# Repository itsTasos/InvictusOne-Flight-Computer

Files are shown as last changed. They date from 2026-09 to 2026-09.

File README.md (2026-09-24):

# InvictusOne Flight Computer

A 4-layer flight-data acquisition and logging board for high-power model rockets. The design combines a 3S LiPo power front end, an STM32G474 microcontroller, multiple flight sensors, non-volatile storage, CAN-FD and UART interfaces, and an external watchdog.

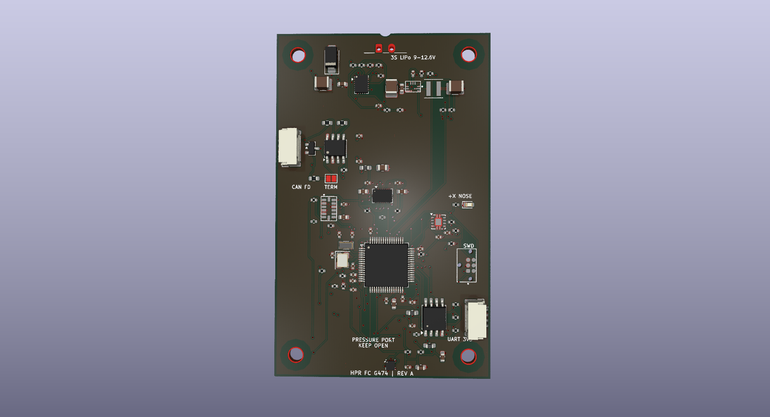
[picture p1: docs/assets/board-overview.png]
KiCad board layout


The board is intended to measure, timestamp, store, and communicate flight data. It does not include ignition, pyrotechnic, or recovery-deployment circuitry.

## Features

- STM32G474RET6 main controller with 8 MHz high-speed and 32.768 kHz low-speed crystals.
- BMI088 accelerometer and gyroscope, plus an ADXL375 high-g accelerometer with a measurement range up to ±200 g.
- LPS22DF absolute pressure sensor for pressure-based altitude estimation in application firmware.
- 128-Mbit (16-MiB) W25Q128 serial NOR flash for flight-data storage.
- CAN-FD transceiver with line protection and selectable 120 Ω termination.
- 3S battery input protection, electronic fuse, battery-current monitoring, and 3.3 V buck conversion.
- External watchdog connected to the MCU reset line.
- 29 test points on the bottom side.

## Specifications

| Item | Design specification |
|---|---|
| Battery input | 3S LiPo, 9.0–12.6 V nominal operating range |
| Battery protection | TPS25940 eFuse; nominal undervoltage rising/falling thresholds of about 8.67 V / 8.14 V, overvoltage cutoff about 13.53 V |
| Input current limit | About 1.74 A, set by the eFuse current-limit resistor |
| Main logic rail | 3.3 V from a TPS62902 synchronous buck converter |
| Sensor rails | 3V3_SENS and 3V3_BARO are ferrite-filtered branches of 3.3 V, not separate regulated outputs |
| Data storage | 128 Mbit / 16 MiB serial NOR flash |
| Communication | CAN-FD, 3.3 V UART, SWD |
| PCB outline | 50 × 80 mm |
| PCB construction | 4 copper layers, nominal 1.6 mm thickness |
| Mounting | Four 3.2 mm non-plated holes on a 40 × 70 mm pattern |
| Test access | 29 bottom-side test points |

Power thresholds and current limit are nominal resistor-based calculations. They are not per-cell LiPo protection thresholds or measured performance limits.

## Main components

| Reference | Part | Function |
|---|---|---|
| U1 | STM32G474RET6 | Main microcontroller; sensor acquisition, logging control, and communications |
| U2 | TPS3431SQDRBRQ1 | External watchdog; its output can reset the MCU |
| U3 | BMI088 | Accelerometer and gyroscope |
| U4 | ADXL375BCCZ | High-g accelerometer, ±200 g range |
| U5 | LPS22DFTR | Absolute pressure sensor |
| U6 | W25Q128JVSIQ | 128-Mbit serial NOR flash |
| U7 | TCAN3413DR | CAN-FD physical-layer transceiver |
| U8 | TPS25940AQRVCRQ1 | Input eFuse, voltage monitoring, current limiting, and current monitor |
| U9 | TPS62902QRYTRQ1 | Battery-to-3.3 V buck converter |
| U10 | PESD2CANFD24VT-Q | CAN bus transient protection |
| D2 | SMAJ13A-TR | Battery-input TVS diode |
| L1 | XGL4020-102ME, 1 µH | Buck-converter power inductor |

## Power and signal architecture

Battery power enters J1 as VBAT_RAW. The input TVS and eFuse feed VBAT_PROTECTED, which supplies the 3.3 V buck converter and is also available at J2 pin 1. The buck output is 3V3_MAIN. Ferrite filters create the 3V3_SENS branch for the inertial sensors, the 3V3_BARO branch for the pressure sensor, and a filtered VDDA branch for the MCU ADC.

The BMI088 uses SPI1, the ADXL375 uses SPI2, the pressure sensor uses I2C3, and the external flash uses SPI3. The MCU connects to the CAN-FD transceiver through FDCAN1, to J3 through USART2, and to a debug probe through SWD at J4. All board domains share a common ground; the sensor supply branches are filtered but not galvanically isolated.

See [Hardware design](docs/hardware-design.md) for the power path and design calculations, [Connector pinout](docs/pinout.md) for connector and test-point details, and [Programming and debug](docs/programming.md) for the custom SWD connection.

## External connectors

| Connector | Pin | Signal |
|---|---:|---|
| J1 — battery | 1 | VBAT_RAW, battery positive |
|  | 2 | GND |
| J2 — CAN module bus | 1 | VBAT_PROTECTED, battery voltage |
|  | 2 | GND |
|  | 3 | CAN_H |
|  | 4 | CAN_L |
| J3 — UART | 1 | 3V3_MAIN |
|  | 2 | GND |
|  | 3 | UART_TX from MCU |
|  | 4 | UART_RX to MCU |
| J4 — SWD | 1 | 3V3_MAIN / target reference |
|  | 2 | SWDIO |
|  | 3 | GND |
|  | 4 | SWCLK |
|  | 5 | GND |
|  | 6 | NRST |

**J2 pin 1 carries protected battery voltage, not 3.3 V.** J3 is a 3.3 V UART interface, not RS-232. J4 uses a custom six-contact assignment and is not the standard TC2030-CTX pinout. Confirm the pin numbering and cable wiring before connecting external equipment.

## Mechanical orientation

The board is 50 × 80 mm. The +X nose direction is marked on the silkscreen along the long board axis. The pressure-sensor port should remain unobstructed when installed. The four mounting holes are non-plated and form a 40 × 70 mm rectangle.

## Repository layout

- hardware/kicad/ — KiCad project, PCB, hierarchical schematic, design rules, and local symbol and footprint libraries.
- docs/schematic.pdf — rendered hierarchical schematic.
- docs/assets/board-overview.png — PCB layout illustration.
- docs/ — hardware overview, connector pinout, and programming guide.

## Opening the design

Open hardware/kicad/HPR_FC_G474_3S.kicad_pro in KiCad. The PCB, hierarchical schematic, local libraries, and design-rule file are kept together under hardware/kicad/; the project uses paths relative to that directory.

## Design boundaries

The board has no battery charger, cell balancer, individual-cell monitor, or guaranteed reverse-polarity protection. The eFuse monitors the pack input as a whole. Its nominal undervoltage threshold is below the safe minimum for some individual 3S LiPo cells, so it must not be used as cell-level protection.

The CAN interface is not galvanically isolated. The input TVS clamp can exceed the eFuse absolute-maximum input voltage under some surge conditions; validate the power source, wiring, and transient environment for the intended installation. This board is a sensing, logging, and communications platform, not a deployment controller.

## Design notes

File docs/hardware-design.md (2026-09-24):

# Hardware design

## Functional overview

The board routes a 3S LiPo input through a transient suppressor and an electronic fuse, then converts the protected battery rail to 3.3 V. The STM32G474 reads the sensors, monitors power, controls the external watchdog, communicates over CAN-FD and UART, and accesses external serial flash for data storage.

The inertial sensors, pressure sensor, MCU, CAN interface, watchdog, and flash share a common ground. Sensor supply branches use ferrite beads and local capacitors for filtering; they are not independent regulators or isolated domains.

## Power path

1. J1 provides VBAT_RAW and ground. D2 (SMAJ13A) is connected across the input for transient suppression.
2. U8 (TPS25940A) provides eFuse functions including undervoltage and overvoltage monitoring, current limiting, controlled output rise, fault indication, and analog current monitoring.
3. VBAT_PROTECTED feeds U9 and is also routed to J2 pin 1.
4. U9 (TPS62902) and L1 generate 3V3_MAIN.
5. FB1 and FB2 with local capacitance form filtered 3V3_SENS and 3V3_BARO branches. FB3 optionally filters the MCU VDDA branch.

With R22 = 442 kΩ, R23 = 20.5 kΩ, and R24 = 36.5 kΩ, nominal resistor-based thresholds are approximately:

| Parameter | Nominal calculation | Result |
|---|---|---:|
| Undervoltage rising | 0.99 × 499 / 57 | 8.67 V |
| Undervoltage falling | 0.93 × 499 / 57 | 8.14 V |
| Overvoltage cutoff | 0.99 × 499 / 36.5 | 13.53 V |
| eFuse current limit | 89 / 51.1, using R25 = 51.1 kΩ | 1.74 A |

These are nominal calculations using the device's typical thresholds and selected resistor values. They are not measurements or cell-level battery protection limits. R32 = 150 kΩ and R33 = 27.4 kΩ divide VBAT_PROTECTED to the MCU ADC. The eFuse current-monitor output is converted through R26 = 18.7 kΩ and routed to an ADC input.

## Processing and sensors

- U1, STM32G474RET6, is the central controller.
- U3, BMI088, provides accelerometer and gyroscope data over SPI1 with separate chip-select and data-ready signals.
- U4, ADXL375, provides high-g acceleration data over SPI2; its specified measurement range is ±200 g.
- U5, LPS22DF, measures absolute pressure over I2C3. Application firmware can use pressure readings to estimate relative altitude.
- U6, W25Q128JV, provides 128 Mbit (16 MiB) of SPI NOR storage over SPI3.
- Y1 and Y2 provide 8 MHz and 32.768 kHz clock references.
- U2, TPS3431, is an external watchdog connected to the MCU watchdog signals and reset net. Firmware must service and configure the watchdog appropriately.

## Communications

U7, TCAN3413, connects the MCU FDCAN1 peripheral to the CAN bus. U10 provides transient protection at the CAN connector. R19 and R20 are fitted 0 Ω links between the transceiver and bus. R21 is a 120 Ω termination resistor; JP1 controls whether the termination is connected. The CAN bus is not isolated.

J3 provides 3.3 V UART through USART2. J4 carries the custom SWD pinout described in [Programming and debug](programming.md).

## PCB and mechanical design

The board outline is 50 × 80 mm with four copper layers and nominal 1.6 mm thickness. Four 3.2 mm non-plated mounting holes use a 40 × 70 mm rectangular pattern. The long axis follows the +X nose direction marked on the board. The pressure-sensor port is identified on the silkscreen and should remain open to ambient pressure.

There are 29 test pads on the bottom side. Their signal groups are listed in [Connector pinout](pinout.md).

## Electrical boundaries

The board does not charge or balance a LiPo pack and does not measure individual cell voltages. The eFuse undervoltage threshold is for pack-level input control and should not be treated as per-cell battery protection. The design has no guaranteed reverse-battery protection. The SMAJ13A TVS clamp can exceed the eFuse absolute-maximum input voltage under some surge conditions, so the source, harness, and transient exposure must be suitable for the selected protection network.

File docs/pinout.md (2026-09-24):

# Connector pinout and test points

## External connectors

| Connector | Pin | Signal | Notes |
|---|---:|---|---|
| J1 — battery | 1 | VBAT_RAW | Battery positive, 9.0–12.6 V for a 3S LiPo |
|  | 2 | GND | Common board ground |
| J2 — CAN module bus | 1 | VBAT_PROTECTED | Protected battery voltage; not 3.3 V |
|  | 2 | GND | Common board ground |
|  | 3 | CAN_H | CAN-FD bus high |
|  | 4 | CAN_L | CAN-FD bus low |
| J3 — UART | 1 | 3V3_MAIN | 3.3 V output |
|  | 2 | GND | Common board ground |
|  | 3 | UART_TX | MCU transmit |
|  | 4 | UART_RX | MCU receive |
| J4 — SWD | 1 | 3V3_MAIN | Debugger target-voltage reference |
|  | 2 | SWDIO | SWD data |
|  | 3 | GND | Common board ground |
|  | 4 | SWCLK | SWD clock |
|  | 5 | GND | Common board ground |
|  | 6 | NRST | MCU reset |

J3 is 3.3 V UART, not RS-232. J4 is a custom pin assignment and does not follow the standard TC2030-CTX mapping. Confirm the connector orientation and pin numbering in the KiCad design before making a cable.

## MCU peripheral allocation

| Peripheral | Connected devices or interface |
|---|---|
| SPI1 | BMI088 |
| SPI2 | ADXL375 |
| SPI3 | W25Q128 serial flash |
| I2C3 | LPS22DF pressure sensor, 7-bit address 0x5C |
| FDCAN1 | TCAN3413 CAN-FD transceiver |
| USART2 | J3 UART connector |
| SWD | J4 debug connector |

The BMI088 accelerometer and gyroscope use separate chip-select signals on SPI1. The ADXL375 has two interrupt outputs. The pressure sensor has an interrupt output. The external watchdog is connected to the MCU reset network.

## Bottom-side test points

| Test point | Signal | Test point | Signal |
|---|---|---|---|
| TP1 | NRST | TP16 | FLASH_CS |
| TP2 | WDG_WDI | TP17 | CAN_H |
| TP3 | WDG_WDO / NRST | TP18 | CAN_L |
| TP4 | SPI1_SCK | TP19 | VBAT_RAW |
| TP5 | SPI1_MISO | TP20 | VBAT_PROTECTED |
| TP6 | SPI1_MOSI | TP21 | 3V3_MAIN |
| TP7 | SPI2_SCK | TP22 | 3V3_SENS |
| TP8 | SPI2_MISO | TP23 | 3V3_BARO |
| TP9 | SPI2_MOSI | TP24 | UART_TX |
| TP10 | I2C3_SCL | TP25 | UART_RX |
| TP11 | I2C3_SDA | TP26 | EFUSE_IMON |
| TP12 | BARO_INT | TP27 | VBAT_SENSE_ADC |
| TP13 | SPI3_SCK | TP28 | EFUSE_FLT |
| TP14 | SPI3_MISO | TP29 | BUCK_PGOOD |
| TP15 | SPI3_MOSI |  |  |

There is no dedicated ground test point; use a verified ground contact such as J1 pin 2. TP3 is labeled for watchdog output but is electrically on the NRST net.

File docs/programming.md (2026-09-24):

# Programming and debug

The STM32G474 is programmed over SWD through J4. The external W25Q128 serial NOR is intended for application data storage; it is not the MCU's program memory.

## J4 to STLINK-V3MINIE STDC14

| J4 pin | Board signal | STDC14 pin |
|---:|---|---:|
| 1 | 3V3_MAIN / target reference | 3, T_VCC |
| 2 | SWDIO | 4 |
| 3 | GND | 5 |
| 4 | SWCLK | 6 |
| 5 | GND | 7 |
| 6 | NRST | 12 |

This table maps electrical contacts, not cable colors. Verify the board connector orientation and continuity through the complete adapter before connecting a probe. J4 is not wired to the standard TC2030-CTX pinout.

## Connection sequence

1. With the board unpowered, connect the debugger to J4 using an adapter wired for the pin mapping above.
2. Power the board separately through J1. Use a supply appropriate for the board input range and observe current during initial power-up.
3. Connect with STM32CubeProgrammer using ST-LINK and SWD.
4. Program the STM32G474 application image, verify the write, and reset the board.

J4 pin 1 is a target-voltage reference from the board. It is not a battery input. Do not connect battery voltage to the debugger's VTref contact. J3 is a separate 3.3 V UART interface and is not RS-232.

## References

- [STLINK-V3MINIE user manual](https://www.st.com/resource/en/user_manual/um2910-stlinkv3minie-evaluation-board-stmicroelectronics.pdf)
- [TC2030-IDC-NL](https://www.tag-connect.com/product/tc2030-idc-nl)
- [STM32CubeProgrammer](https://www.st.com/en/development-tools/stm32cubeprog.html)

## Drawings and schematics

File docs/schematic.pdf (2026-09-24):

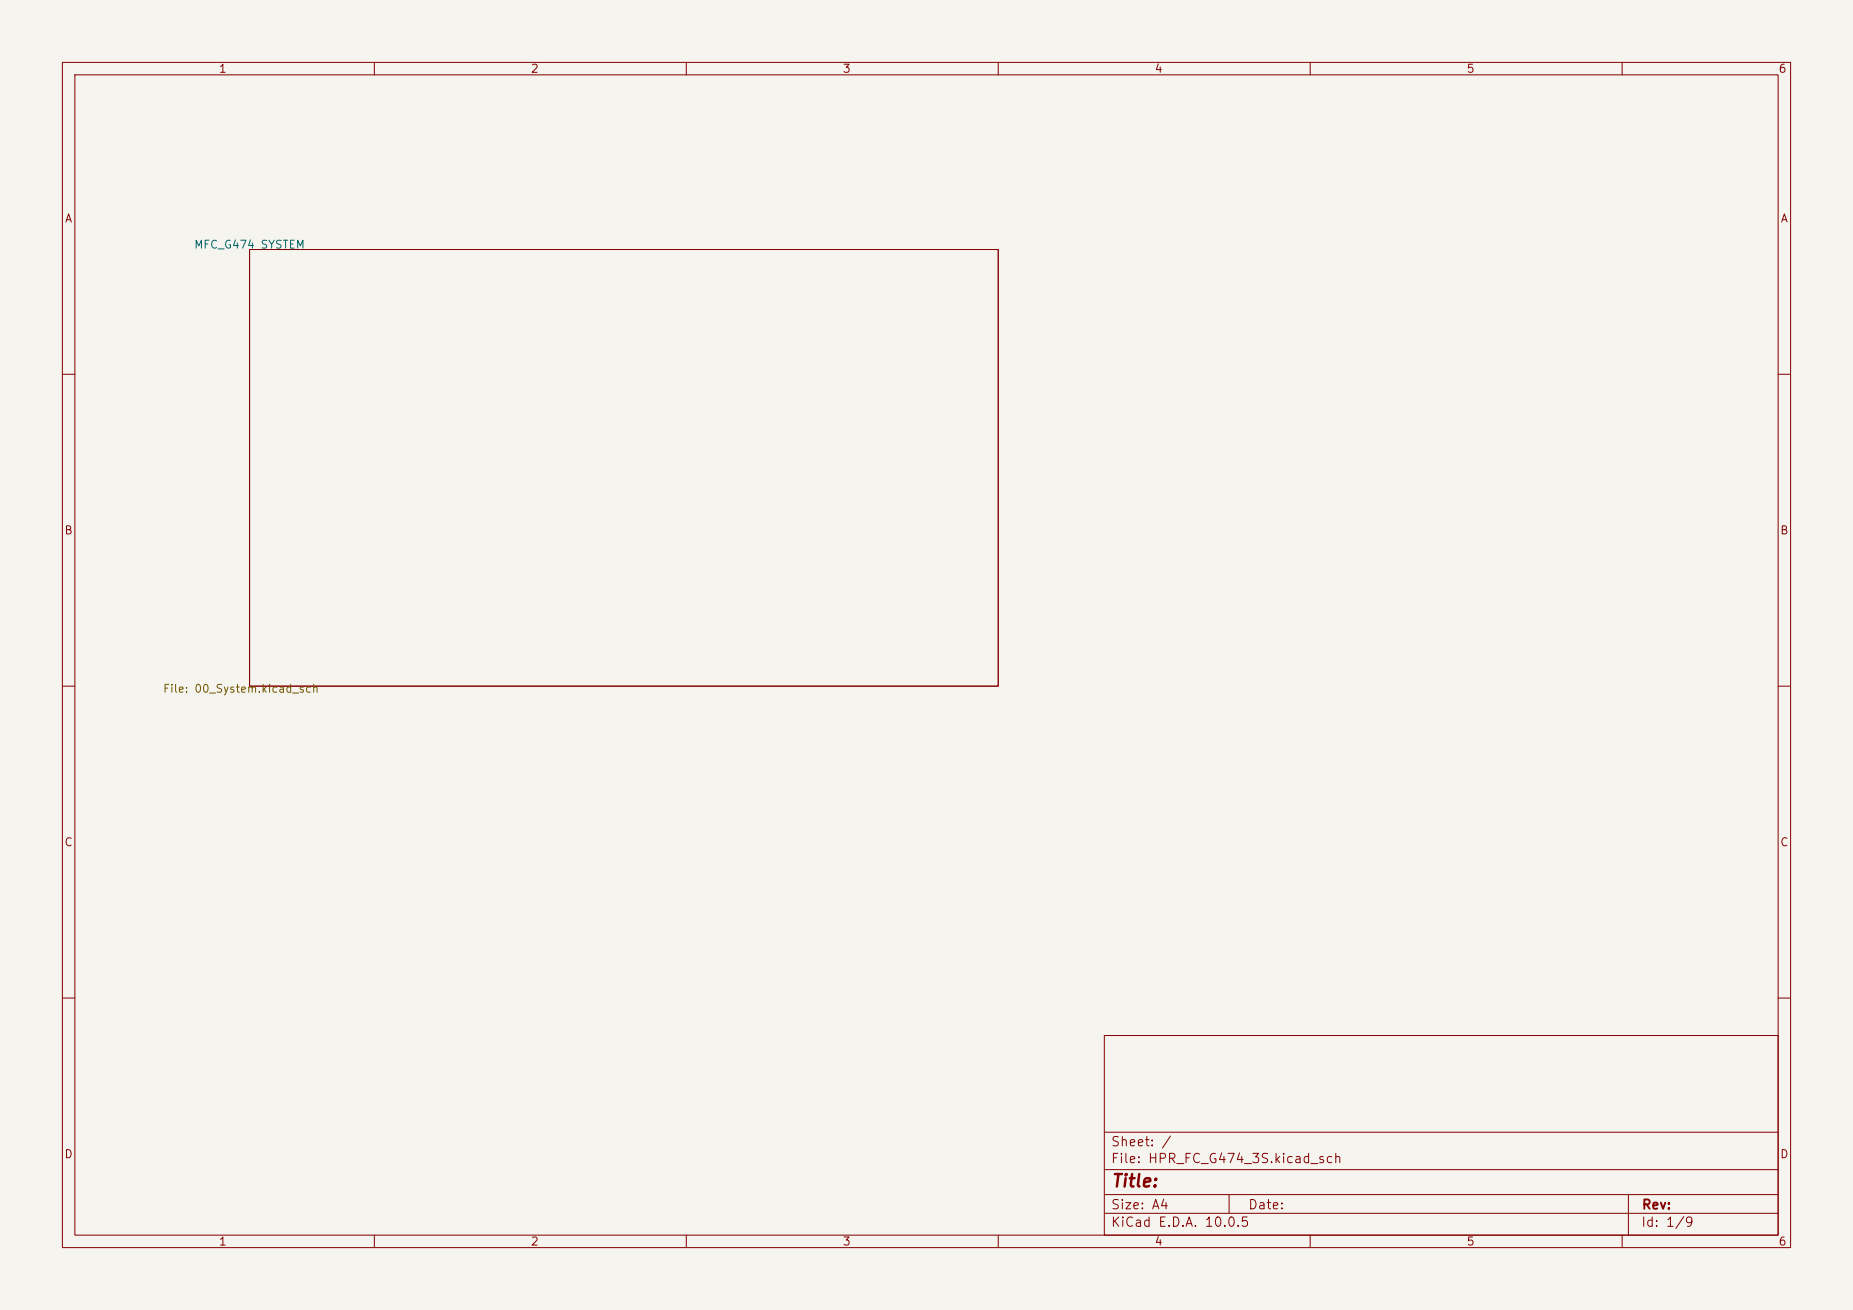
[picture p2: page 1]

Size: A4 | Rev:
KiCad E.D.A. 10.0.5 | Id: 1/9

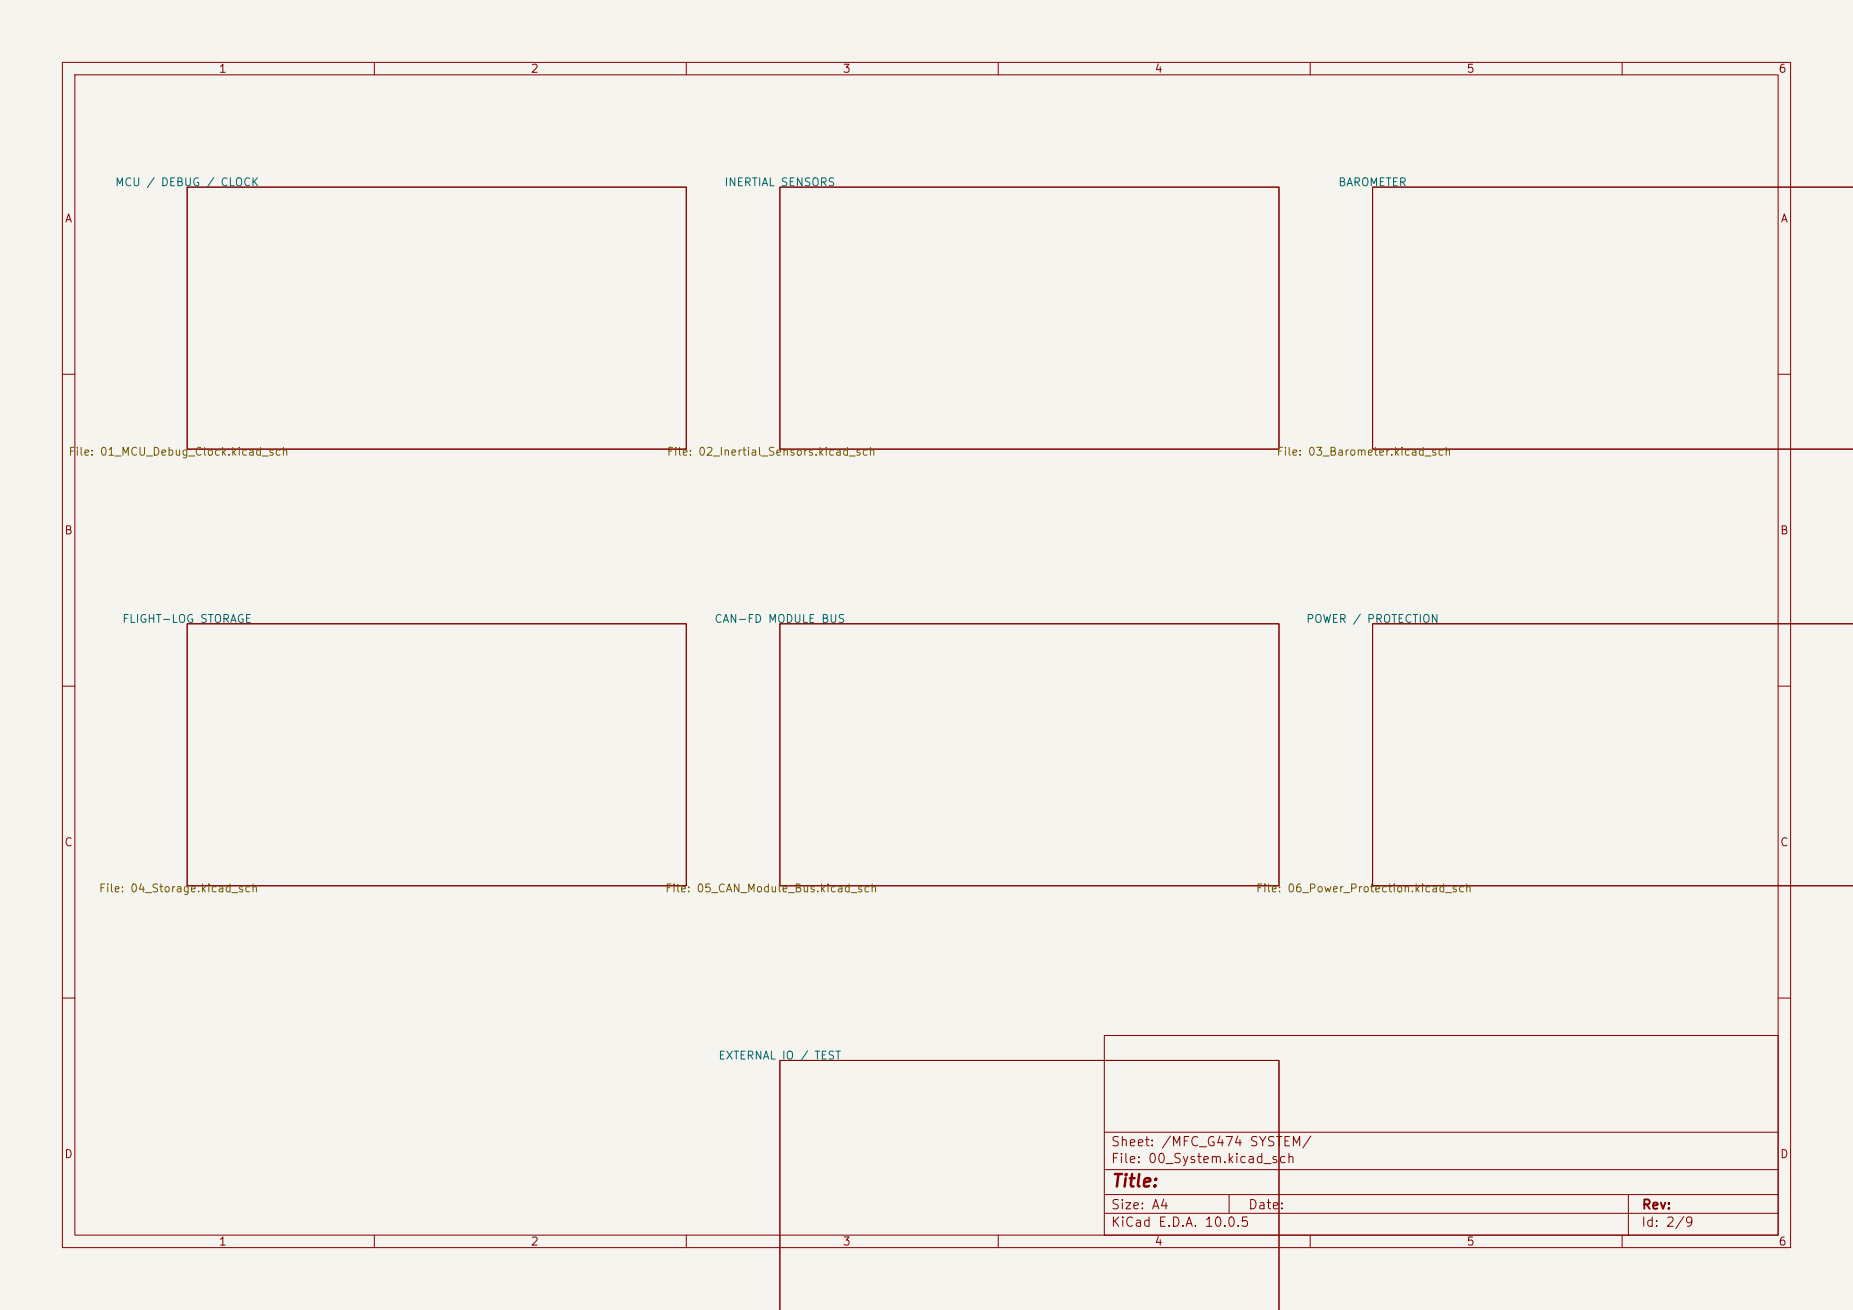
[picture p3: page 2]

File: 03_Barometer.kicad_sch MCU / DEBUG / CLOCK

EXTERNAL IO / TEST File: 07_External_IO.kicad_sch

Sheet: /MFC_G474 SYSTEM/ File: 00_System.kicad_sch | D Date:

Title:

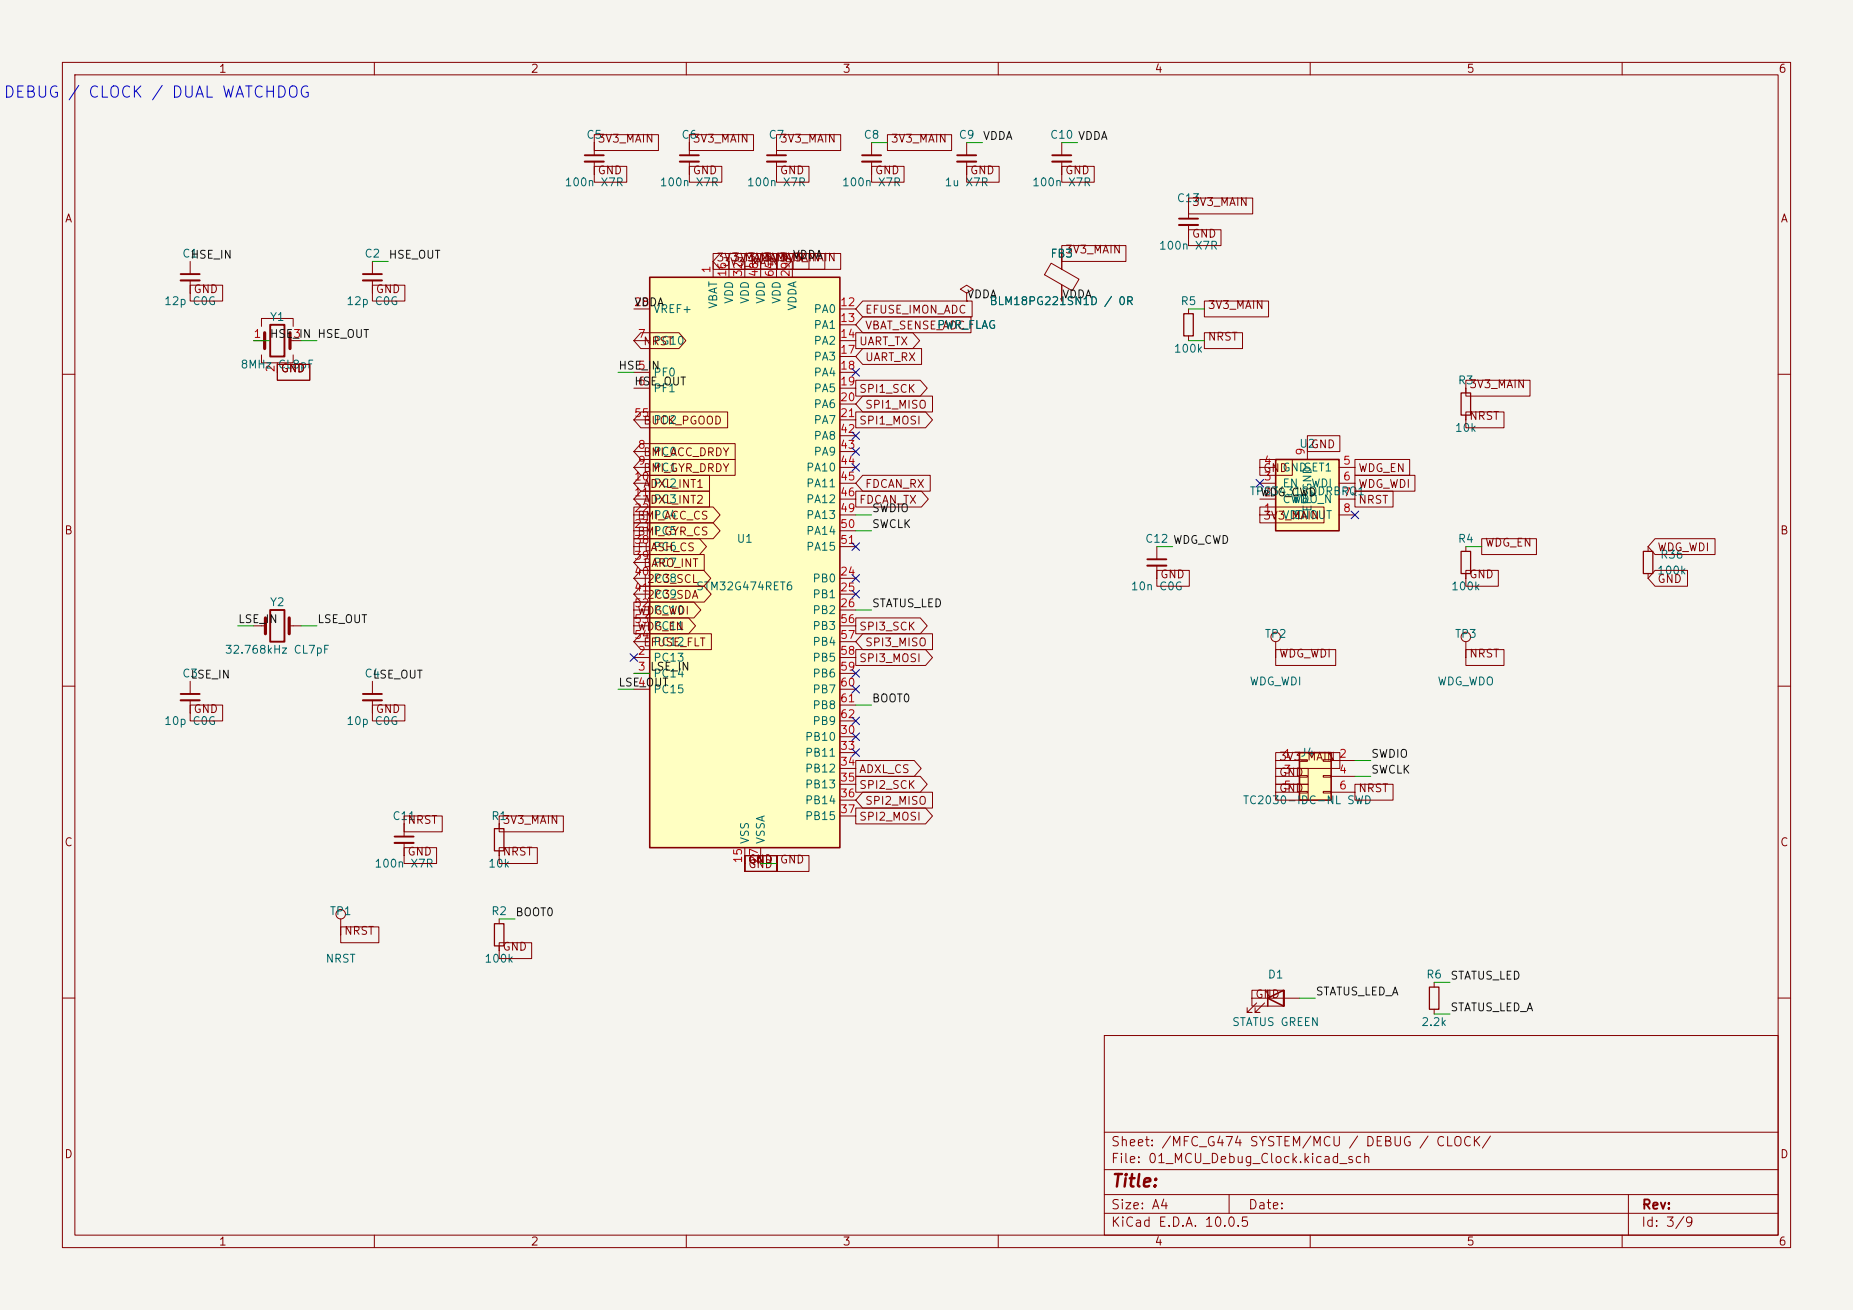
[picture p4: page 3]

VDDA MCU / DEBUG / CLOCK / DUAL WATCHDOG

Sheet: /MFC_G474 SYSTEM/MCU / DEBUG / CLOCK/
File: 01_MCU_Debug_Clock.kicad_sch
Title:

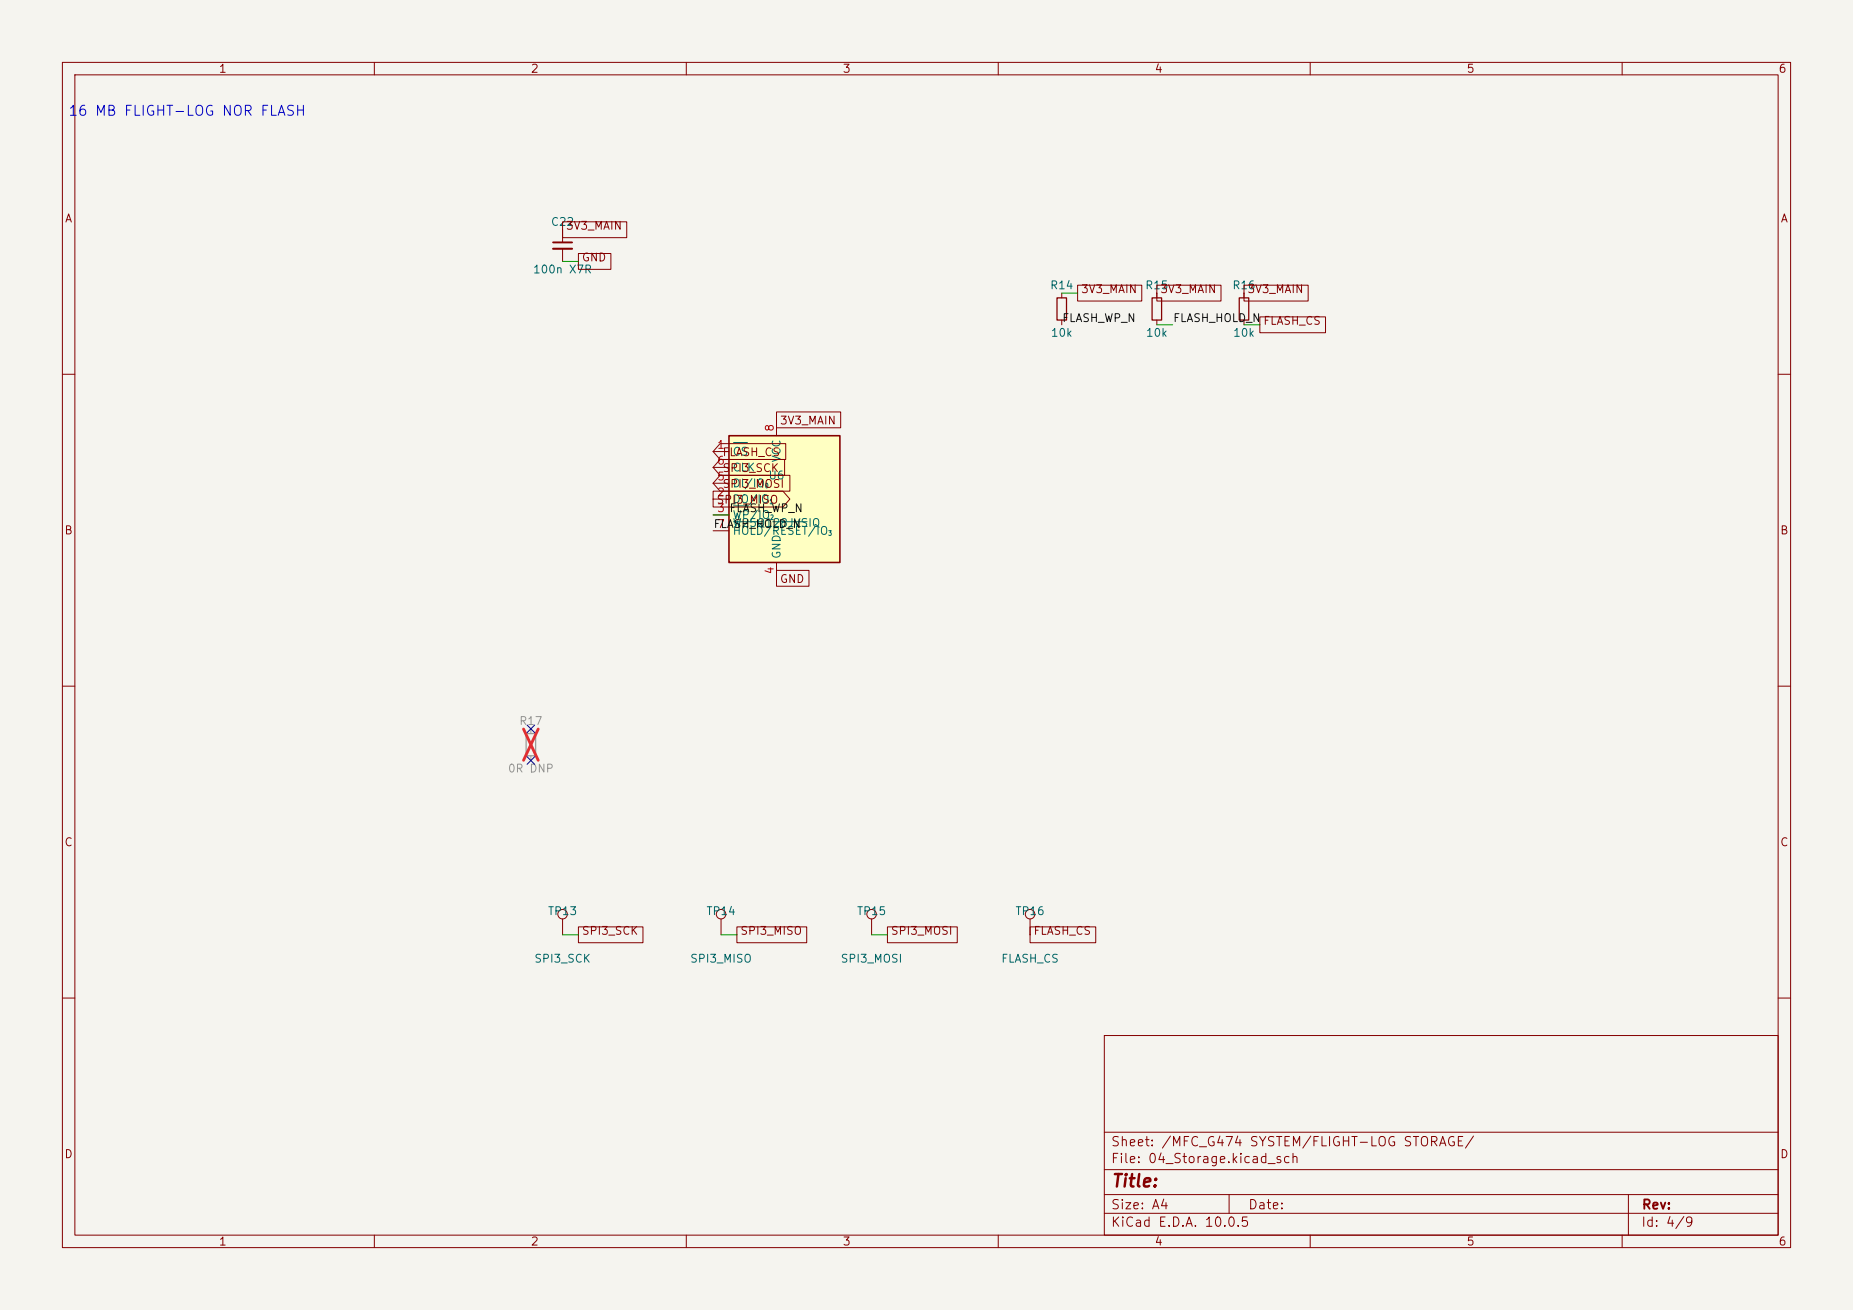
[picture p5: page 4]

FLASH_HOLD_N 16 MB FLIGHT-LOG NOR FLASH

4 DI/IO0 5 CLK 6 HOLD/RESET/IO3 7 VCC

Sheet: /MFC_G474 SYSTEM/FLIGHT-LOG STORAGE/
File: 04_Storage.kicad_sch
Title:

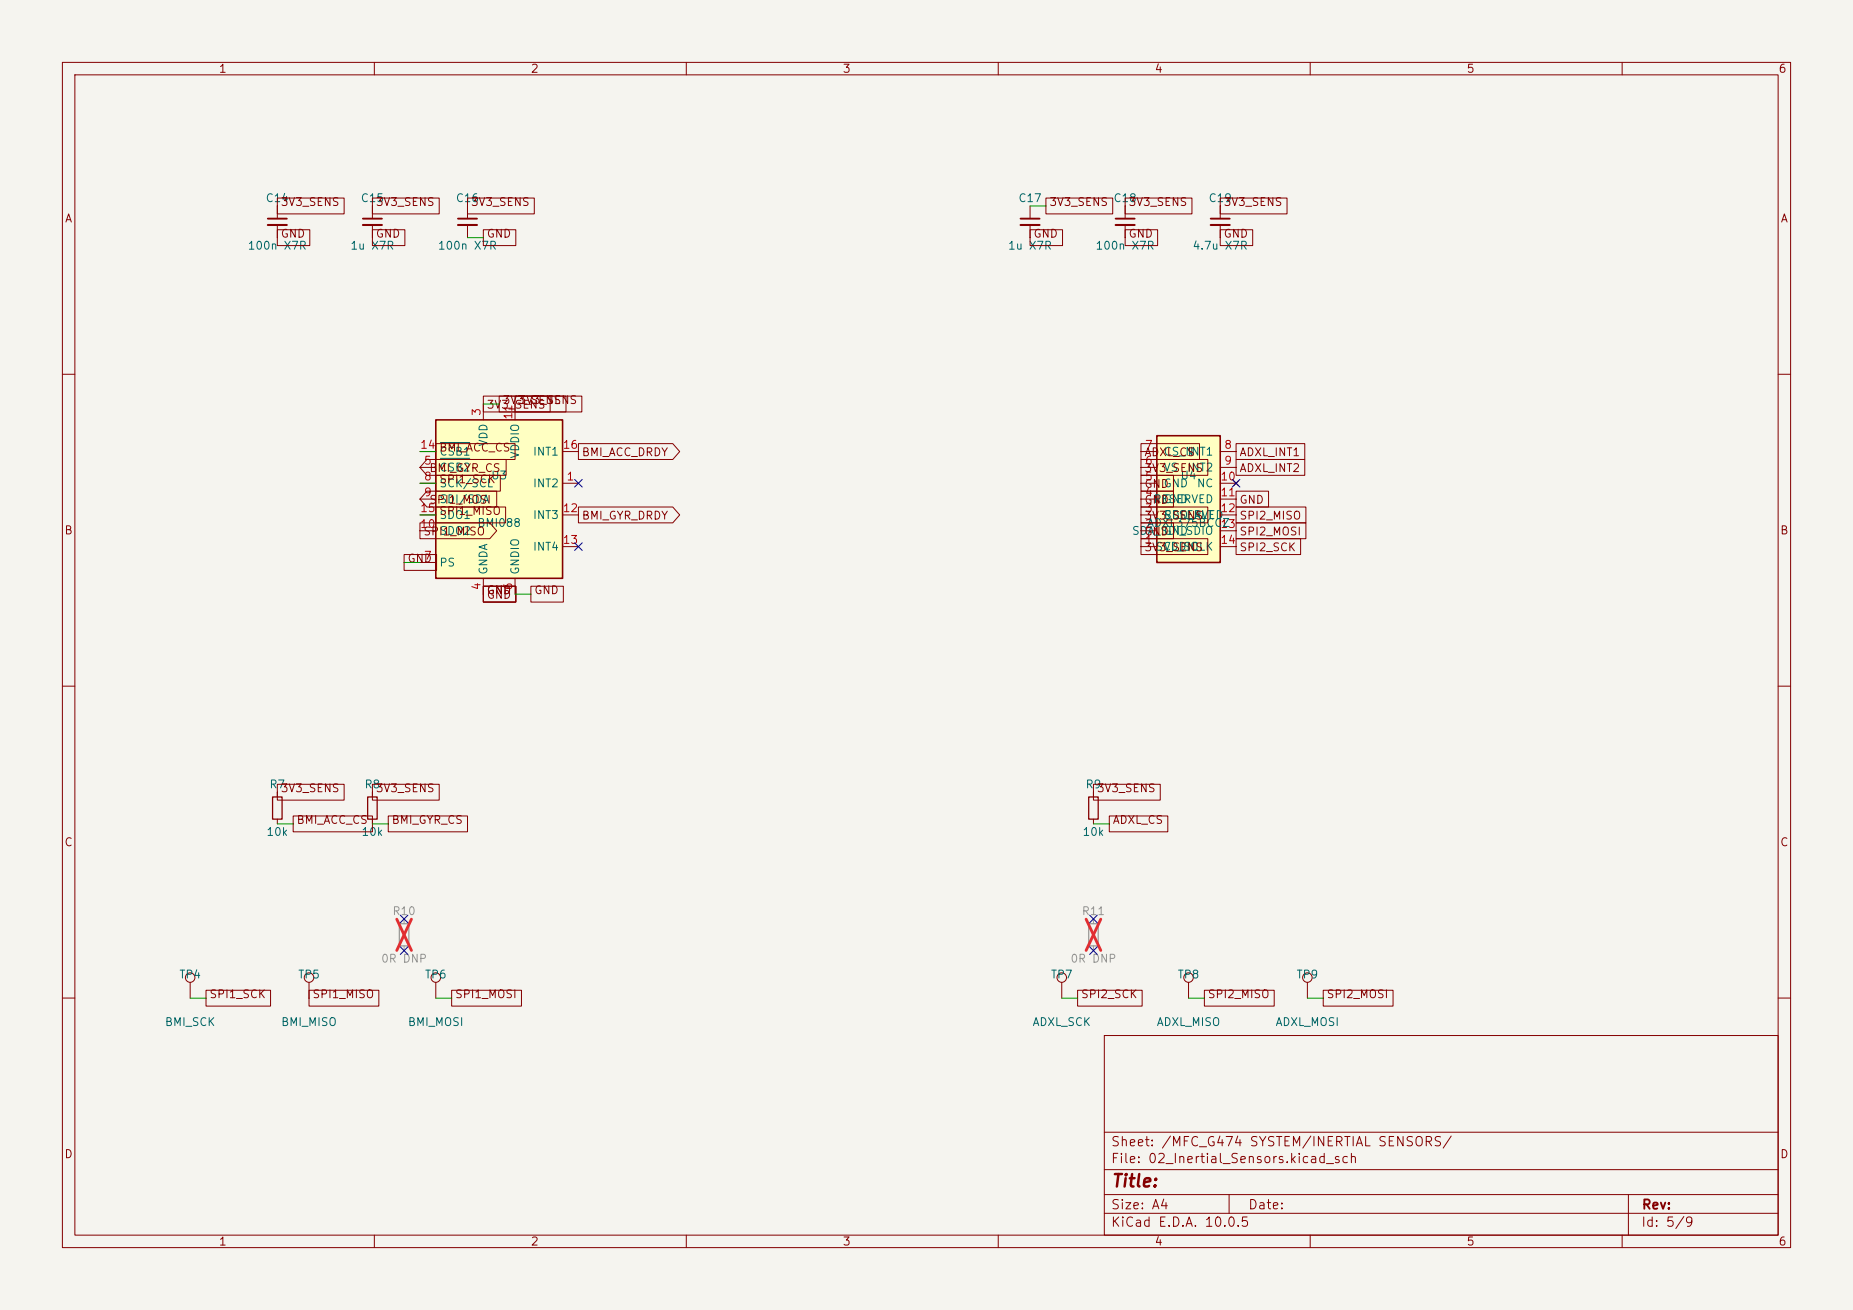
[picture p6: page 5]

Sheet: /MFC_G474 SYSTEM/INERTIAL SENSORS/
File: 02_Inertial_Sensors.kicad_sch
Title:

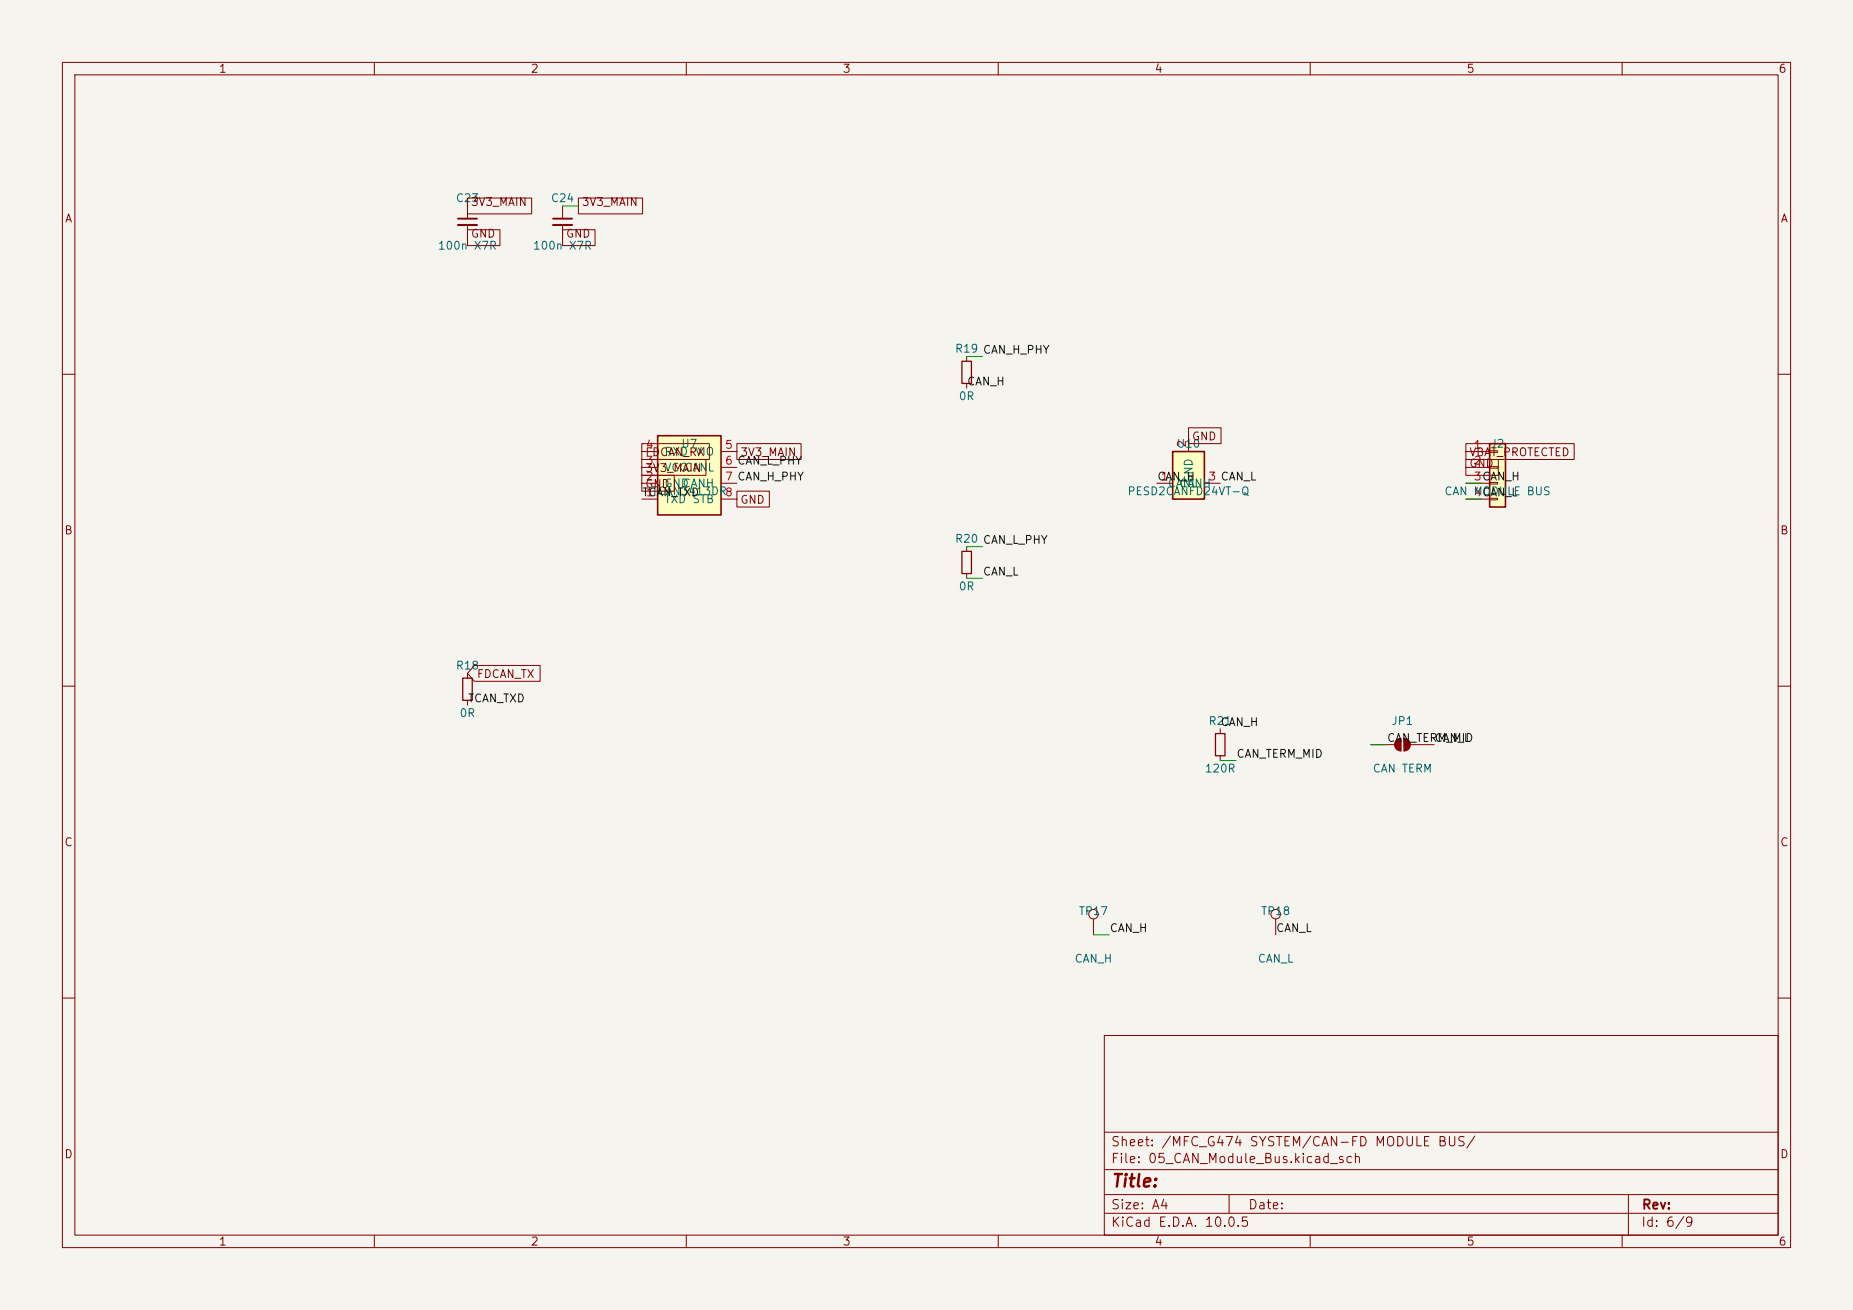
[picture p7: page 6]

Sheet: /MFC_G474 SYSTEM/CAN-FD MODULE BUS/
File: 05_CAN_Module_Bus.kicad_sch
Title:

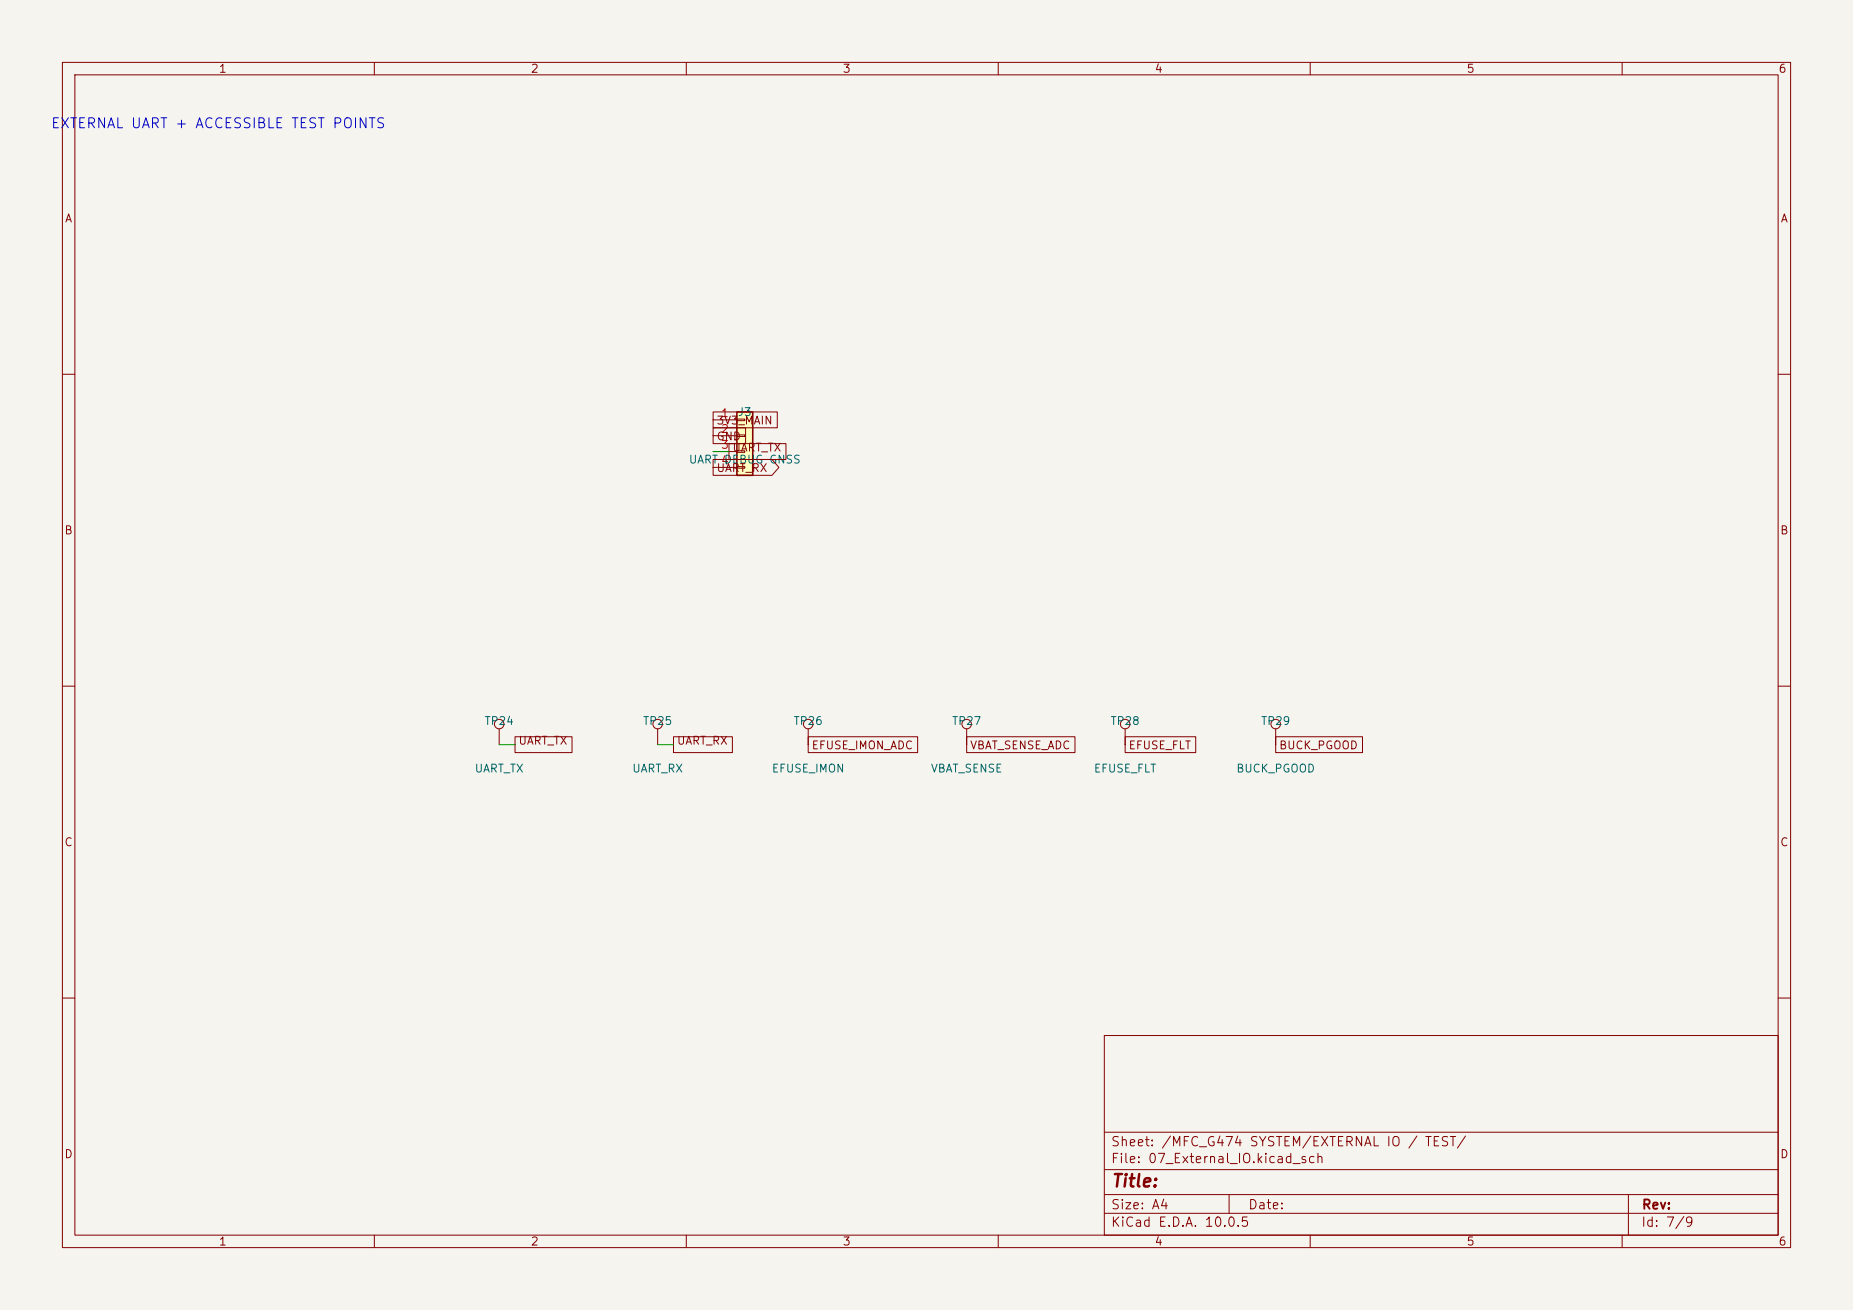
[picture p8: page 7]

UART_RX EXTERNAL UART + ACCESSIBLE TEST POINTS

Sheet: /MFC_G474 SYSTEM/EXTERNAL IO / TEST/
File: 07_External_IO.kicad_sch
Title:

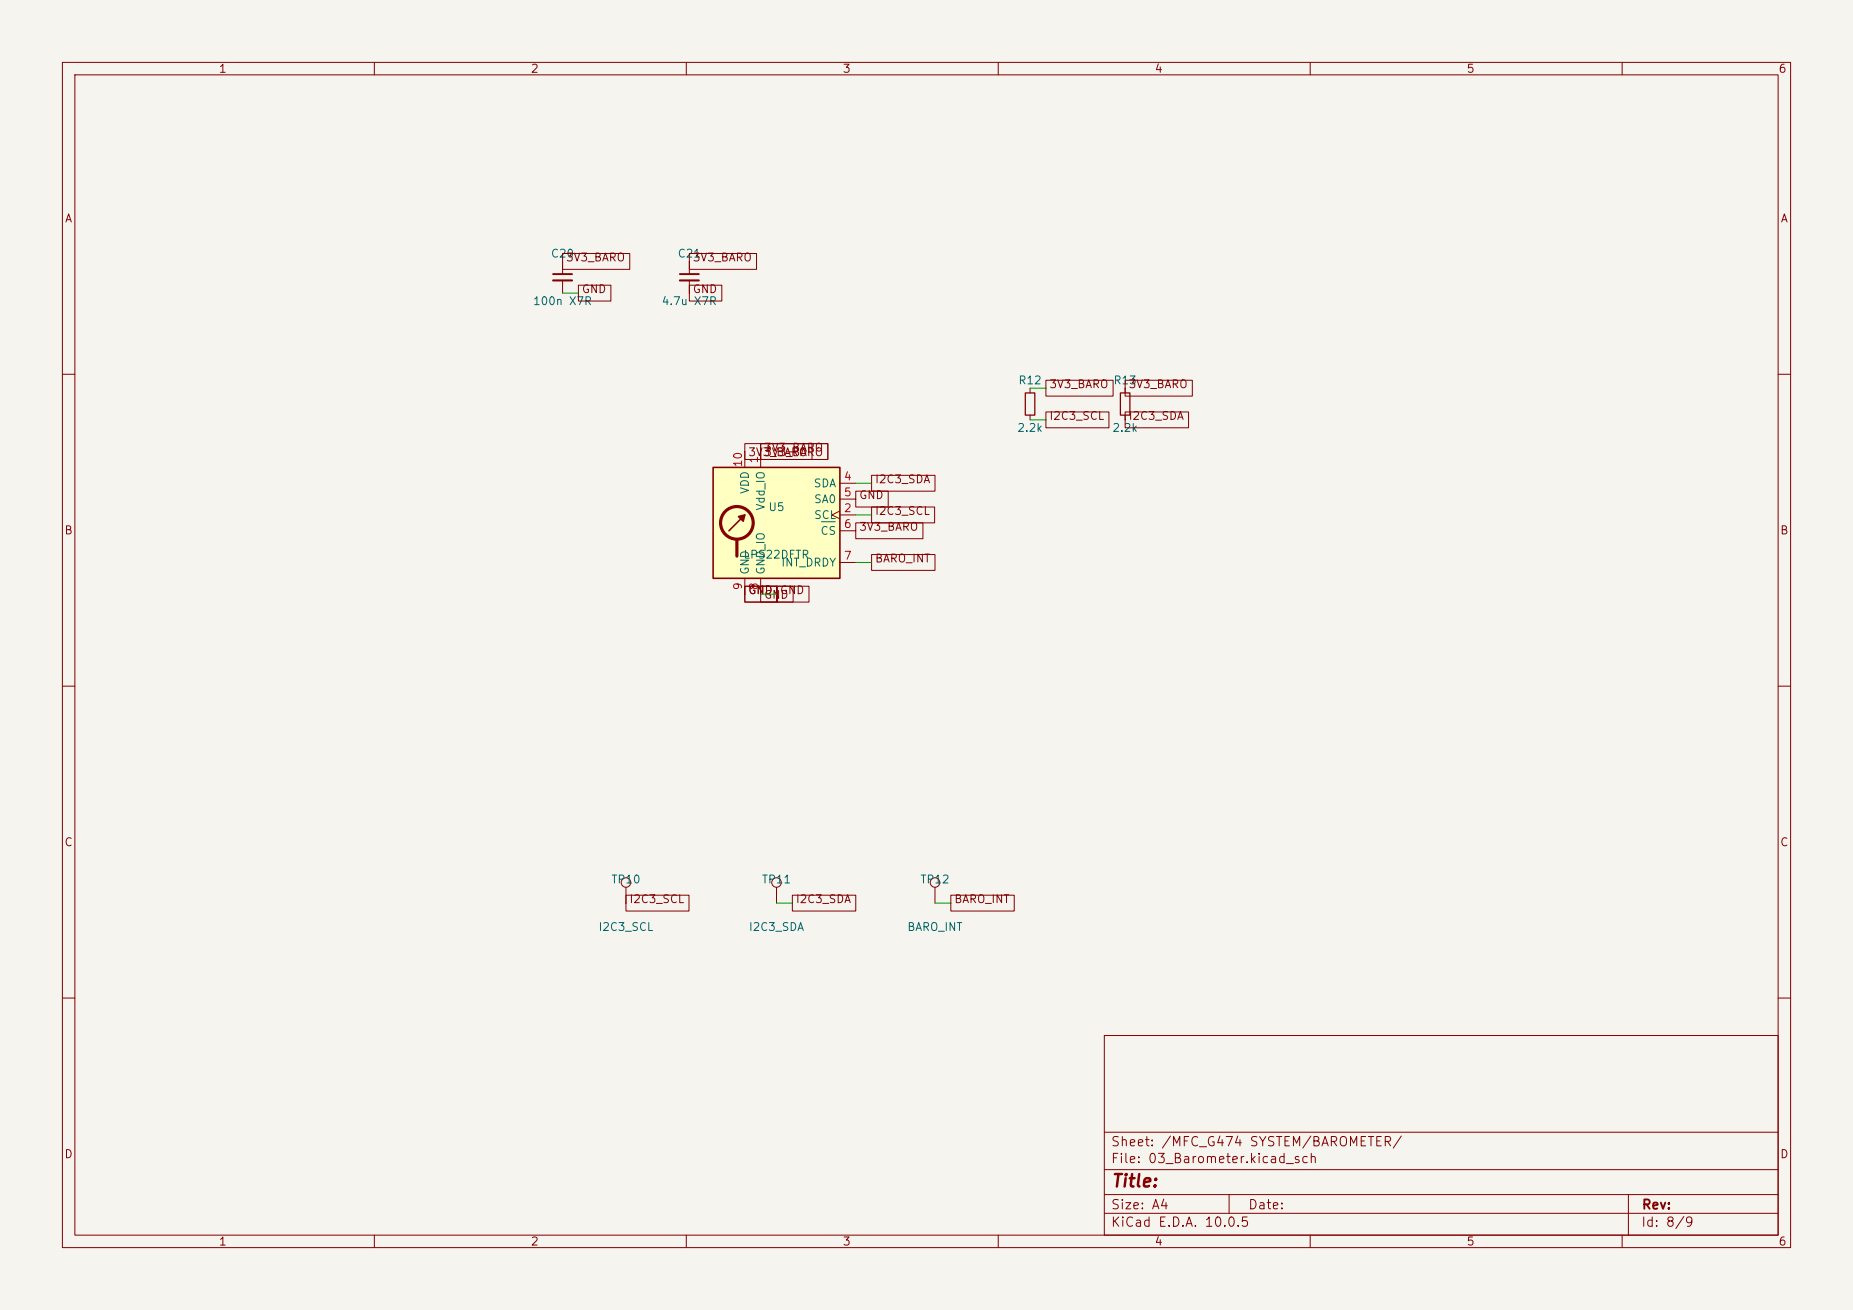
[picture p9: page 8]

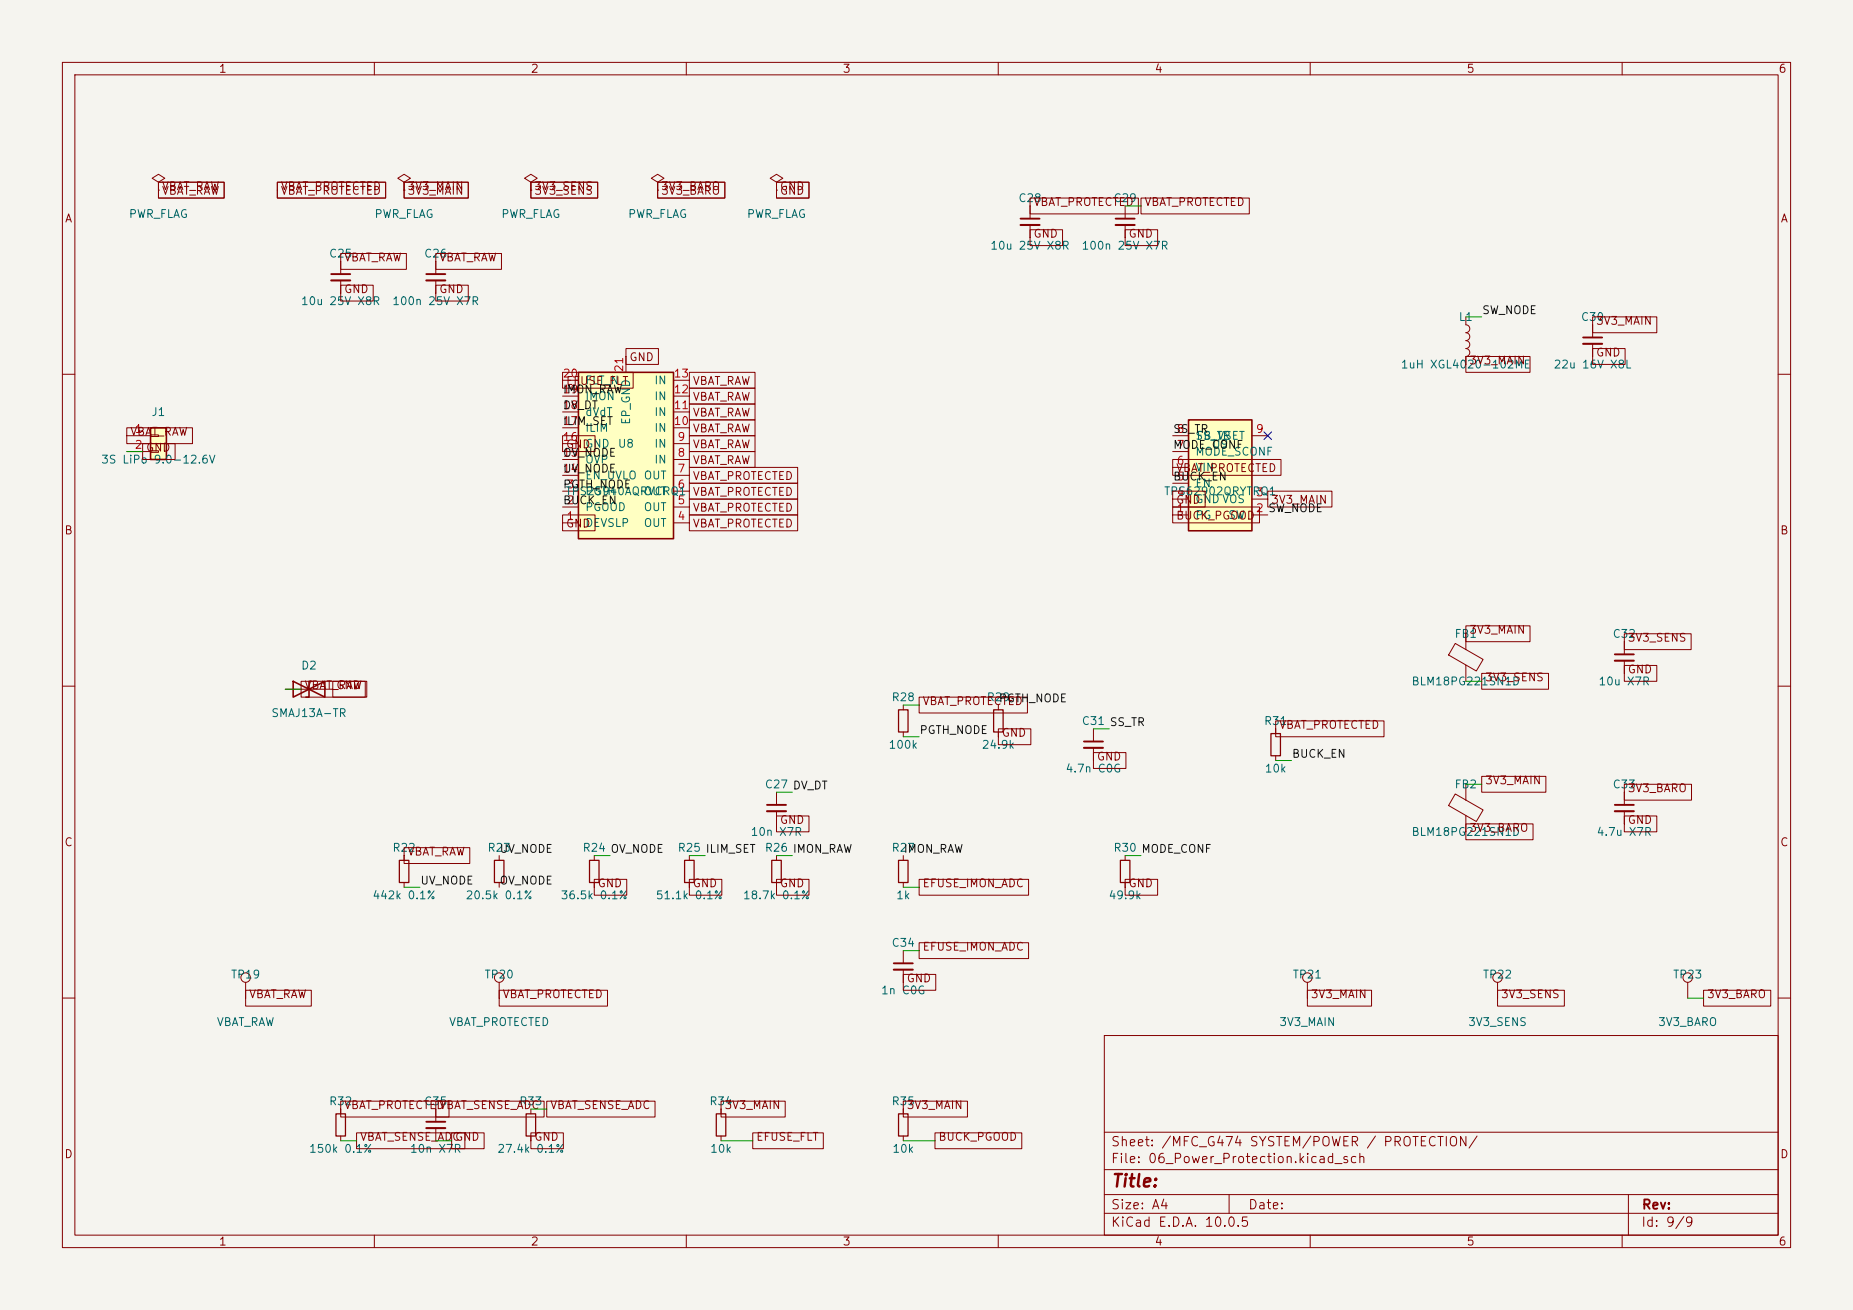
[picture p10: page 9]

Sheet: /MFC_G474 SYSTEM/POWER / PROTECTION/
File: 06_Power_Protection.kicad_sch
Title:

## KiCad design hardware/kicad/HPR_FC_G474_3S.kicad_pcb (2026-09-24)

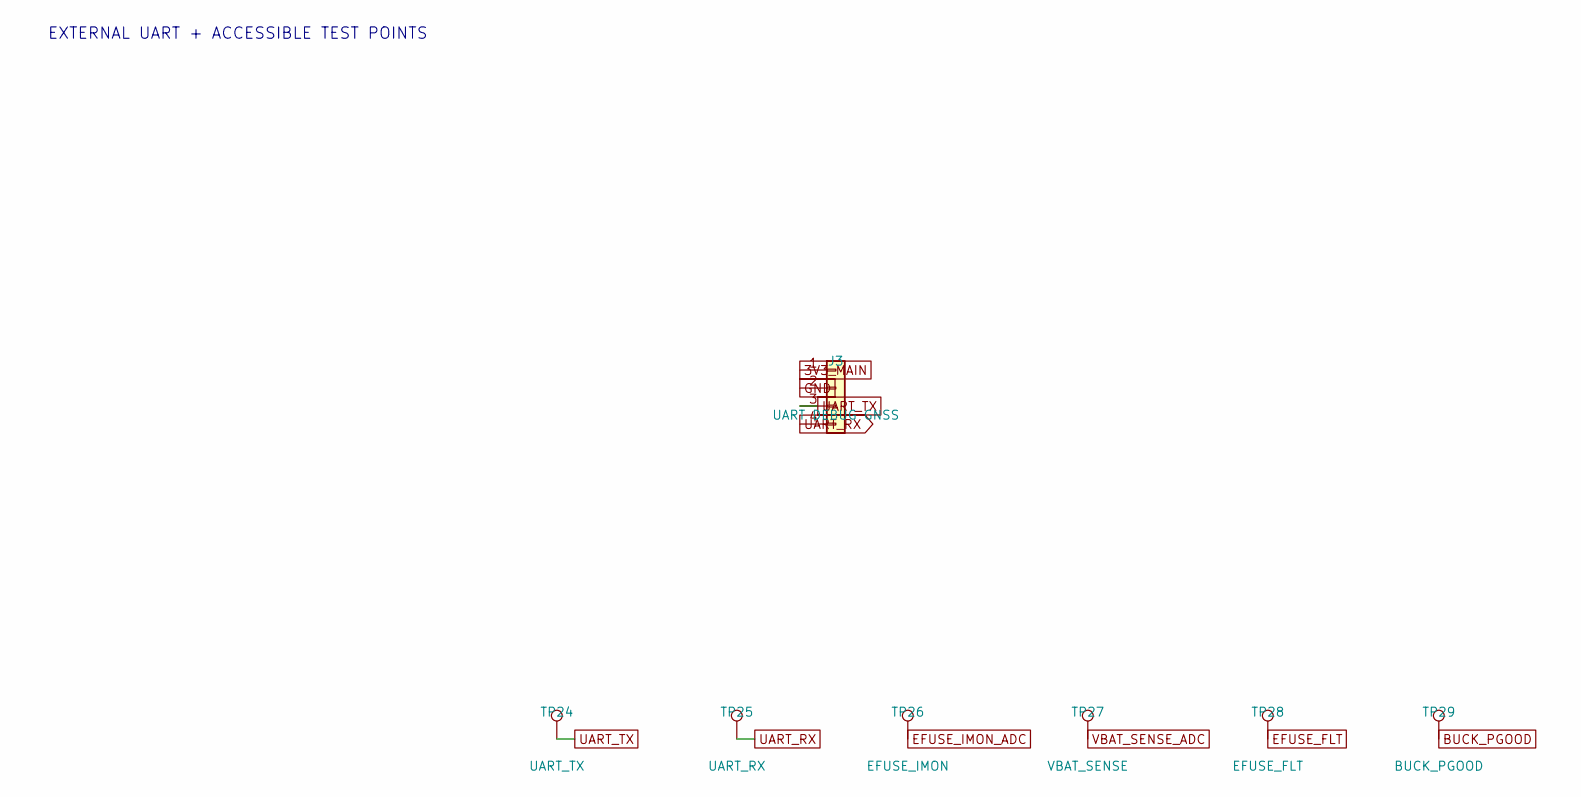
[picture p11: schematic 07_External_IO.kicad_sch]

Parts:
J3: UART DEBUG GNSS; JST_GH_SM04B-GHS-TB_1x04-1MP_P1.25mm_Horizontal
TP24: UART_TX; TestPoint_Pad_D1.0mm
TP25: UART_RX; TestPoint_Pad_D1.0mm
TP26: EFUSE_IMON; TestPoint_Pad_D1.0mm
TP27: VBAT_SENSE; TestPoint_Pad_D1.0mm
TP28: EFUSE_FLT; TestPoint_Pad_D1.0mm
TP29: BUCK_PGOOD; TestPoint_Pad_D1.0mm

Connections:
3V3_MAIN: J3.1; also elsewhere on the board
BUCK_PGOOD: TP29.1 (1_1); also elsewhere on the board
EFUSE_FLT: TP28.1 (1_1); also elsewhere on the board
EFUSE_IMON_ADC: TP26.1 (1_1); also elsewhere on the board
GND: J3.2; also elsewhere on the board
UART_RX: J3.4, TP25.1 (1_1); also elsewhere on the board
UART_TX: J3.3, TP24.1 (1_1); also elsewhere on the board
VBAT_SENSE_ADC: TP27.1 (1_1); also elsewhere on the board

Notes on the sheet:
EXTERNAL UART + ACCESSIBLE TEST POINTS

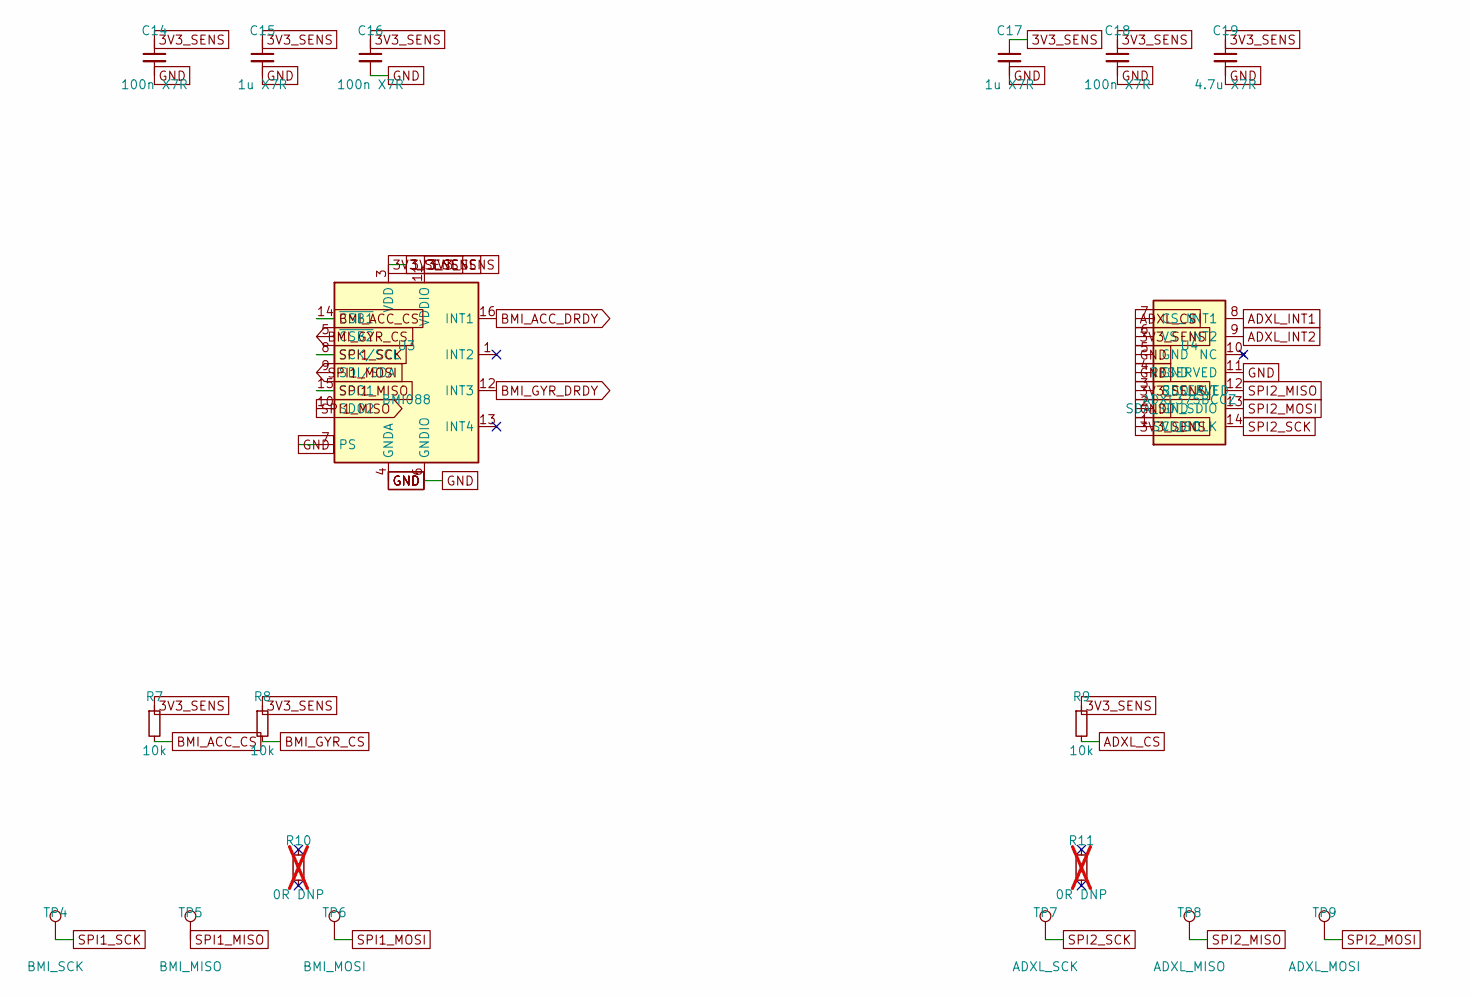
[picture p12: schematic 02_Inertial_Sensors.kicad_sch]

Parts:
C14, C16, C18: 100n X7R; C_0402_1005Metric
C15, C17: 1u X7R; C_0603_1608Metric
C19: 4.7u X7R; C_0603_1608Metric
R7, R8, R9: 10k; R_0402_1005Metric
R10, R11: 0R DNP; R_0402_1005Metric; not fitted
TP4: BMI_SCK; TestPoint_Pad_D1.0mm
TP5: BMI_MISO; TestPoint_Pad_D1.0mm
TP6: BMI_MOSI; TestPoint_Pad_D1.0mm
TP7: ADXL_SCK; TestPoint_Pad_D1.0mm
TP8: ADXL_MISO; TestPoint_Pad_D1.0mm
TP9: ADXL_MOSI; TestPoint_Pad_D1.0mm
U3: BMI088; Bosch_LGA-16_4.5x3mm_P0.5mm_LayoutBorder7x1y_ClockwisePinNu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; MPN BMI088
U4: ADXL375BCCZ; Analog_ADXL375_CC-14-1_LGA14_3x5mm_P0.8mm; MPN ADXL375BCCZ

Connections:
3V3_SENS: C14.1, C15.1, C16.1, C17.1, C18.1, C19.1, R7.1, R8.1, R9.1, U3.3 (VDD), U3.11 (VDDIO), U4.1 (VDDIO), U4.3 (RESERVED), U4.6 (VS); also elsewhere on the board
ADXL_CS: R9.2, U4.7 (CS_N); also elsewhere on the board
ADXL_INT1: U4.8 (INT1); also elsewhere on the board
ADXL_INT2: U4.9 (INT2); also elsewhere on the board
BMI_ACC_CS: R7.2, U3.14 (~CSB1); also elsewhere on the board
BMI_ACC_DRDY: U3.16 (INT1); also elsewhere on the board
BMI_GYR_CS: R8.2, U3.5 (~CSB2); also elsewhere on the board
BMI_GYR_DRDY: U3.12 (INT3); also elsewhere on the board
GND: C14.2, C15.2, C16.2, C17.2, C18.2, C19.2, U3.2 (GNDA), U3.4 (GNDA), U3.6 (GNDIO), U3.7 (PS), U4.2 (GND), U4.4 (GND), U4.5 (GND), U4.11 (RESERVED); also elsewhere on the board
SPI1_MISO: TP5.1 (1_1), U3.10 (SDO2), U3.15 (SDO1); also elsewhere on the board
SPI1_MOSI: TP6.1 (1_1), U3.9 (SDI/SDA); also elsewhere on the board
SPI1_SCK: TP4.1 (1_1), U3.8 (SCK/SCL); also elsewhere on the board
SPI2_MISO: TP8.1 (1_1), U4.12 (SDO_ALT); also elsewhere on the board
SPI2_MOSI: TP9.1 (1_1), U4.13 (SDA_SDI_SDIO); also elsewhere on the board
SPI2_SCK: TP7.1 (1_1), U4.14 (SCL_SCLK); also elsewhere on the board

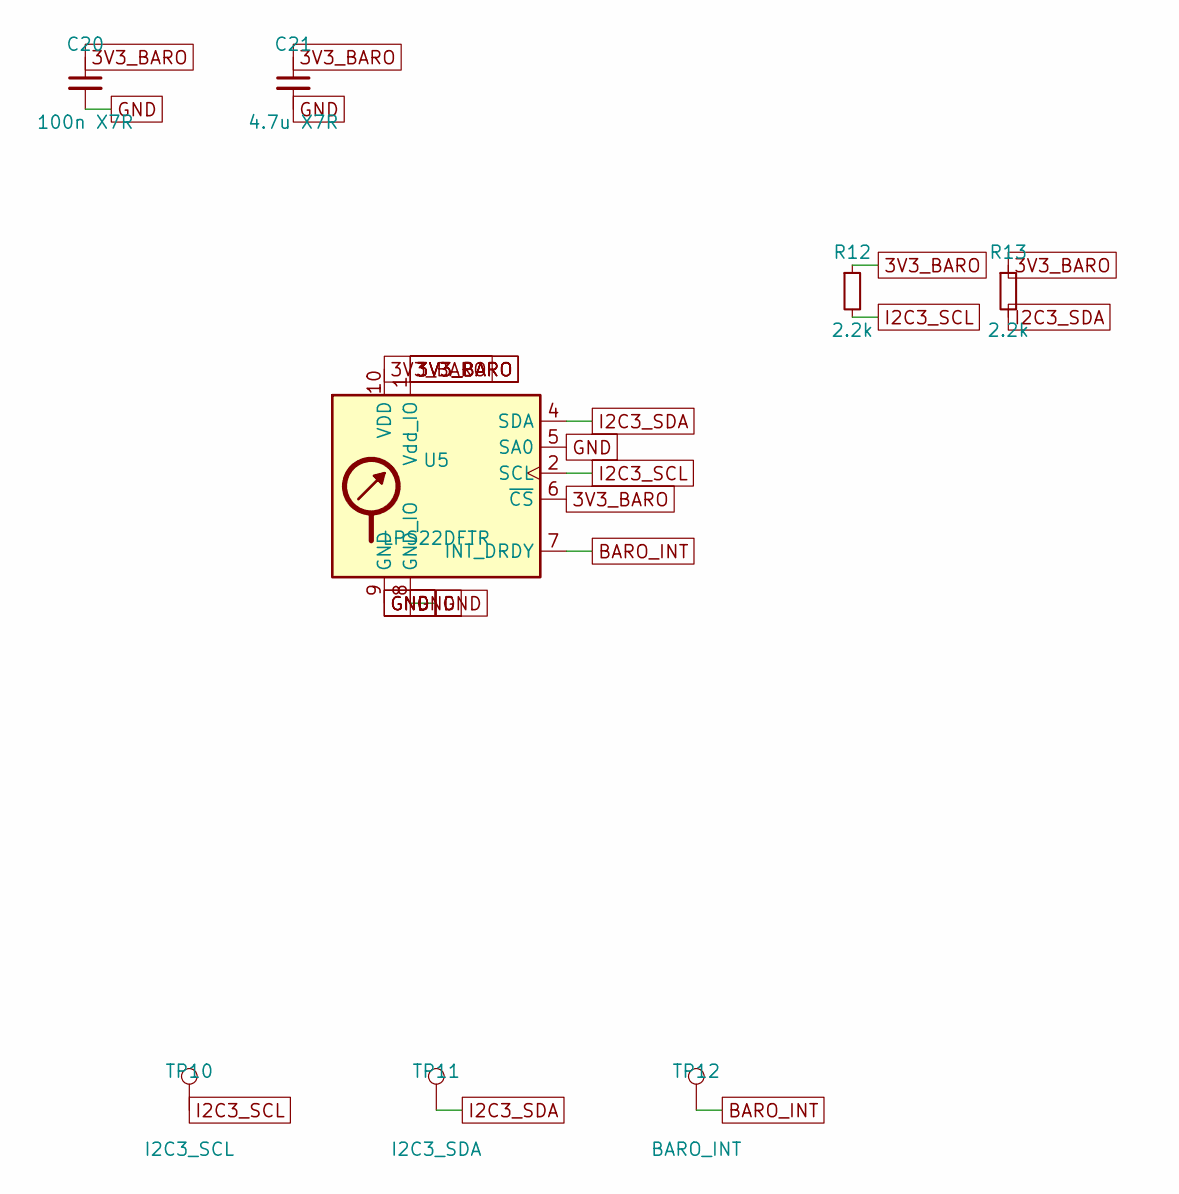
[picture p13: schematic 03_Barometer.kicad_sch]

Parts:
C20: 100n X7R; C_0402_1005Metric
C21: 4.7u X7R; C_0603_1608Metric
R12, R13: 2.2k; R_0402_1005Metric
TP10: I2C3_SCL; TestPoint_Pad_D1.0mm
TP11: I2C3_SDA; TestPoint_Pad_D1.0mm
TP12: BARO_INT; TestPoint_Pad_D1.0mm
U5: LPS22DFTR; ST_HLGA-10_2x2mm_P0.5mm_LayoutBorder3x2y; MPN LPS22DFTR

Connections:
3V3_BARO: C20.1, C21.1, R12.1, R13.1, U5.1 (Vdd_IO), U5.6 (~CS), U5.10 (VDD); also elsewhere on the board
BARO_INT: TP12.1 (1_1), U5.7 (INT_DRDY); also elsewhere on the board
GND: C20.2, C21.2, U5.3 (GND), U5.5 (SA0), U5.8 (GND_IO), U5.9 (GND); also elsewhere on the board
I2C3_SCL: R12.2, TP10.1 (1_1), U5.2 (SCL); also elsewhere on the board
I2C3_SDA: R13.2, TP11.1 (1_1), U5.4 (SDA); also elsewhere on the board

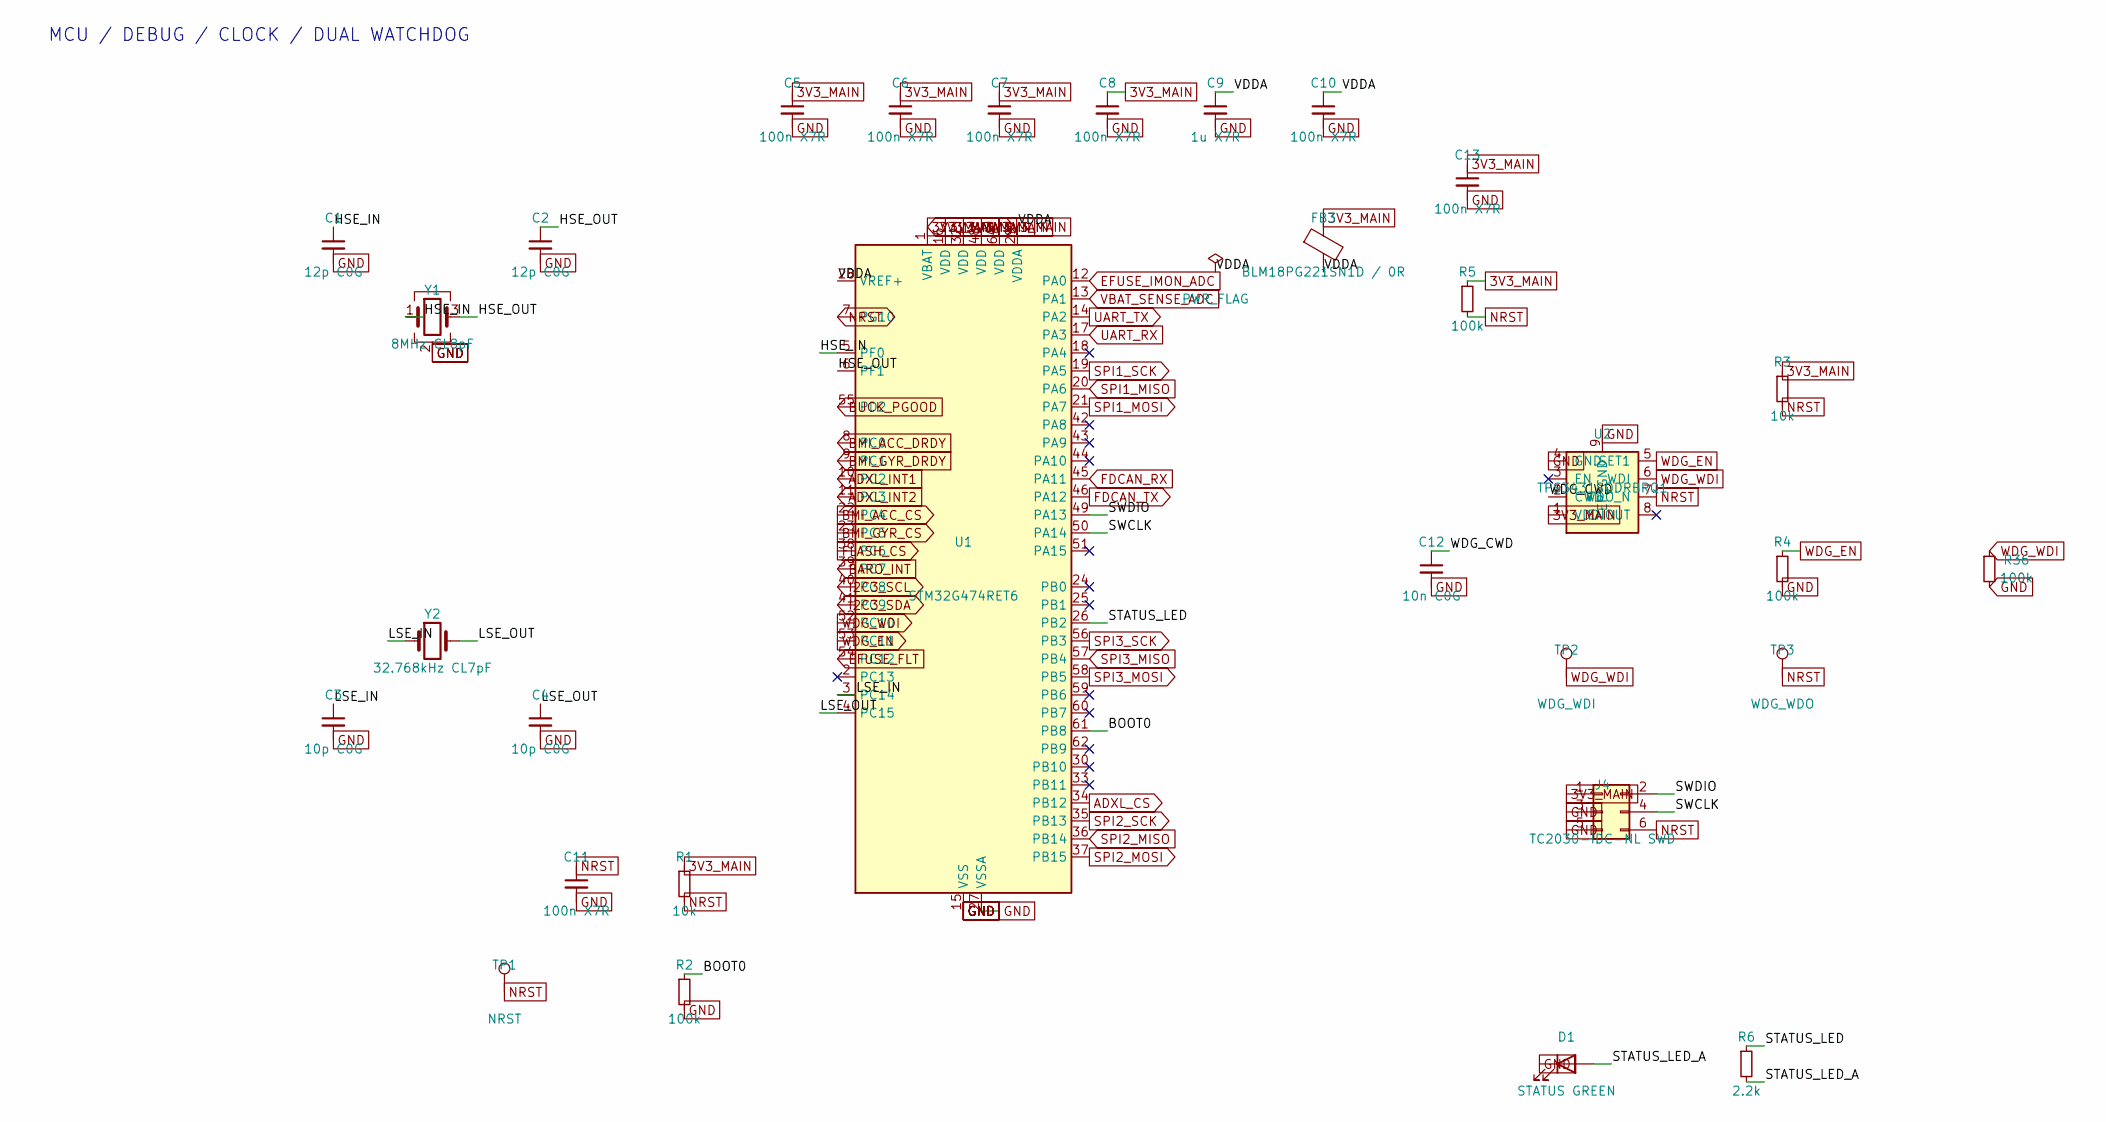
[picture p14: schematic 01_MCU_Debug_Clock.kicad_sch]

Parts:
C1, C2: 12p C0G; C_0402_1005Metric
C3, C4: 10p C0G; C_0402_1005Metric
C5, C6, C7, C8, C10, C11, C13: 100n X7R; C_0402_1005Metric
C9: 1u X7R; C_0603_1608Metric
C12: 10n C0G; C_0402_1005Metric
D1: STATUS GREEN; LED_0603_1608Metric
FB3: BLM18PG221SN1D / 0R; L_0603_1608Metric_Pad1.05x0.95mm_HandSolder; MPN BLM18PG221SN1D
J4: TC2030-IDC-NL SWD; TagConnect_TC2030-IDC-NL
R1, R3: 10k; R_0402_1005Metric
R2, R4, R5, R36: 100k; R_0402_1005Metric
R6: 2.2k; R_0402_1005Metric
TP1: NRST; TestPoint_Pad_D1.0mm
TP2: WDG_WDI; TestPoint_Pad_D1.0mm
TP3: WDG_WDO; TestPoint_Pad_D1.0mm
U1: STM32G474RET6; LQFP-64_10x10mm_P0.5mm; MPN STM32G474RET6
U2: TPS3431SQDRBRQ1; HPR_U2_verified_geometry; MPN TPS3431SQDRBRQ1
Y1: 8MHz CL8pF; Crystal_SMD_3225-4Pin_3.2x2.5mm; MPN ECS-80-8-33-JGN-TR3
Y2: 32.768kHz CL7pF; Crystal_SMD_3215-2Pin_3.2x1.5mm; MPN ABS07-32.768KHZ-7-T

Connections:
3V3_MAIN: C5.1, C6.1, C7.1, C8.1, C13.1, FB3.1, J4.1, R1.1, R3.1, R5.1, U1.1 (VBAT), U1.16 (VDD), U1.32 (VDD), U1.48 (VDD), U1.64 (VDD), U2.1 (VDD); also elsewhere on the board
/MFC_G474 SYSTEM/MCU / DEBUG / CLOCK/BOOT0: R2.1, U1.61 (PB8)
/MFC_G474 SYSTEM/MCU / DEBUG / CLOCK/HSE_IN: C1.1, U1.5 (PF0), Y1.1
/MFC_G474 SYSTEM/MCU / DEBUG / CLOCK/HSE_OUT: C2.1, U1.6 (PF1), Y1.3
/MFC_G474 SYSTEM/MCU / DEBUG / CLOCK/LSE_IN: C3.1, U1.3 (PC14), Y2.1
/MFC_G474 SYSTEM/MCU / DEBUG / CLOCK/LSE_OUT: C4.1, U1.4 (PC15), Y2.2
/MFC_G474 SYSTEM/MCU / DEBUG / CLOCK/STATUS_LED: R6.1, U1.26 (PB2)
/MFC_G474 SYSTEM/MCU / DEBUG / CLOCK/STATUS_LED_A: D1.2 (A), R6.2
/MFC_G474 SYSTEM/MCU / DEBUG / CLOCK/SWCLK: J4.4, U1.50 (PA14)
/MFC_G474 SYSTEM/MCU / DEBUG / CLOCK/SWDIO: J4.2, U1.49 (PA13)
/MFC_G474 SYSTEM/MCU / DEBUG / CLOCK/VDDA: C9.1, C10.1, FB3.2, U1.28 (VREF+), U1.29 (VDDA)
/MFC_G474 SYSTEM/MCU / DEBUG / CLOCK/WDG_CWD: C12.1, U2.2 (CWD)
ADXL_CS: U1.34 (PB12); also elsewhere on the board
ADXL_INT1: U1.10 (PC2); also elsewhere on the board
ADXL_INT2: U1.11 (PC3); also elsewhere on the board
BARO_INT: U1.39 (PC7); also elsewhere on the board
BMI_ACC_CS: U1.22 (PC4); also elsewhere on the board
BMI_ACC_DRDY: U1.8 (PC0); also elsewhere on the board
BMI_GYR_CS: U1.23 (PC5); also elsewhere on the board
BMI_GYR_DRDY: U1.9 (PC1); also elsewhere on the board
BUCK_PGOOD: U1.55 (PD2); also elsewhere on the board
EFUSE_FLT: U1.54 (PC12); also elsewhere on the board
EFUSE_IMON_ADC: U1.12 (PA0); also elsewhere on the board
FDCAN_RX: U1.45 (PA11); also elsewhere on the board
FDCAN_TX: U1.46 (PA12); also elsewhere on the board
FLASH_CS: U1.38 (PC6); also elsewhere on the board
GND: C1.2, C2.2, C3.2, C4.2, C5.2, C6.2, C7.2, C8.2, C9.2, C10.2, C11.2, C12.2, C13.2, D1.1 (K), J4.3, J4.5, R2.2, R4.2, R36.2, U1.15 (VSS), U1.27 (VSSA), U1.31 (VSS), U1.47 (VSS), U1.63 (VSS), U2.4 (GND), U2.9 (EP_GND), Y1.2 (G), Y1.4 (G); also elsewhere on the board
I2C3_SCL: U1.40 (PC8); also elsewhere on the board
I2C3_SDA: U1.41 (PC9); also elsewhere on the board
NRST: C11.1, J4.6, R1.2, R3.2, R5.2, TP1.1 (1_1), TP3.1 (1_1), U1.7 (PG10), U2.7 (WDO_N)
SPI1_MISO: U1.20 (PA6); also elsewhere on the board
SPI1_MOSI: U1.21 (PA7); also elsewhere on the board
SPI1_SCK: U1.19 (PA5); also elsewhere on the board
SPI2_MISO: U1.36 (PB14); also elsewhere on the board
SPI2_MOSI: U1.37 (PB15); also elsewhere on the board
SPI2_SCK: U1.35 (PB13); also elsewhere on the board
SPI3_MISO: U1.57 (PB4); also elsewhere on the board
SPI3_MOSI: U1.58 (PB5); also elsewhere on the board
SPI3_SCK: U1.56 (PB3); also elsewhere on the board
UART_RX: U1.17 (PA3); also elsewhere on the board
UART_TX: U1.14 (PA2); also elsewhere on the board
VBAT_SENSE_ADC: U1.13 (PA1); also elsewhere on the board
WDG_EN: R4.1, U1.53 (PC11), U2.5 (SET1)
WDG_WDI: R36.1, TP2.1 (1_1), U1.52 (PC10), U2.6 (WDI)

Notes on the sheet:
MCU / DEBUG / CLOCK / DUAL WATCHDOG

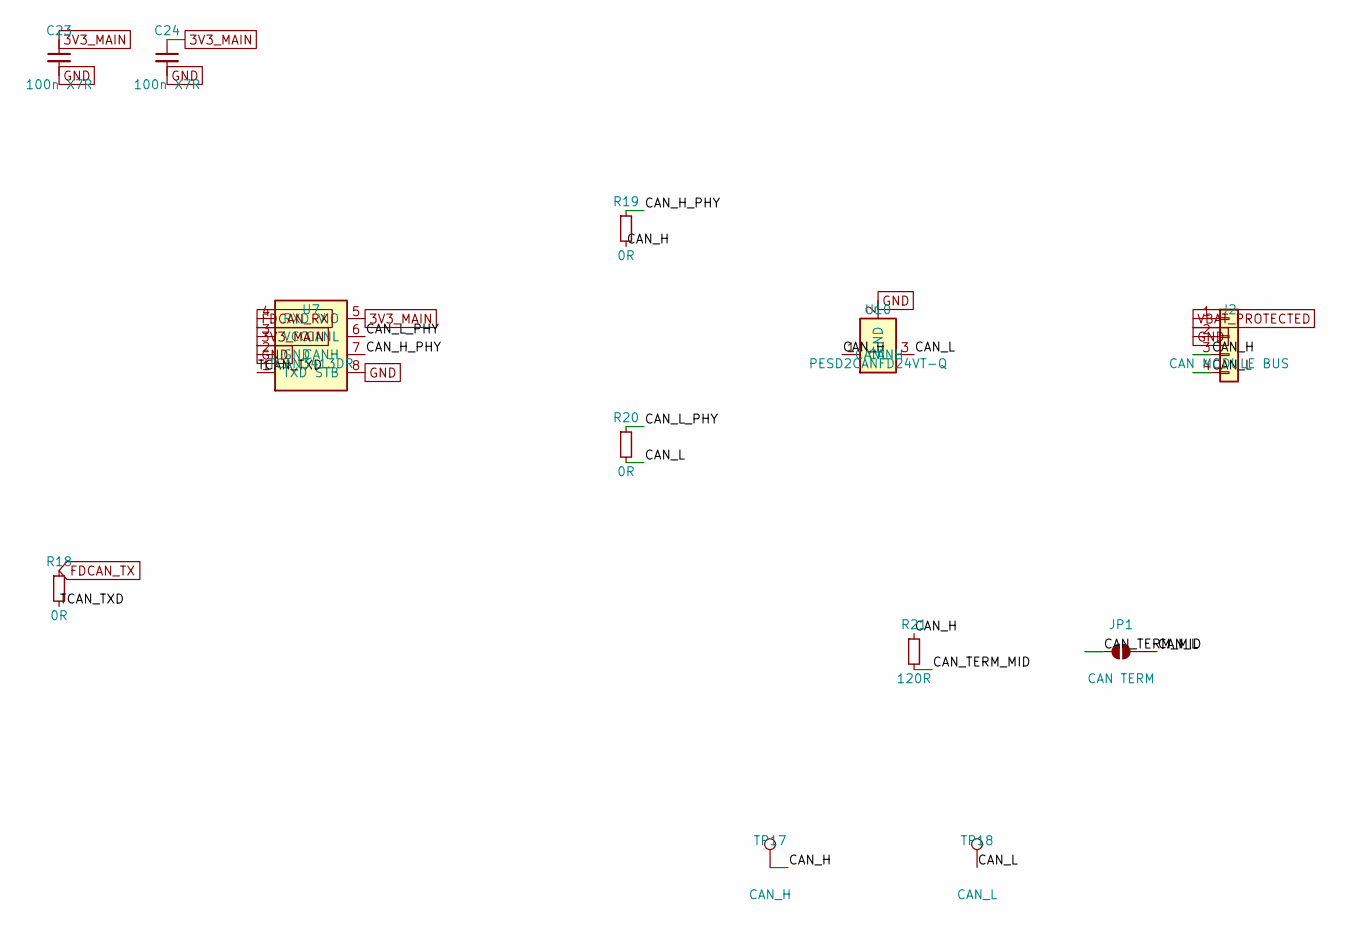
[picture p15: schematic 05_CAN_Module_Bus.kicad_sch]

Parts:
C23, C24: 100n X7R; C_0402_1005Metric
J2: CAN MODULE BUS; JST_GH_SM04B-GHS-TB_1x04-1MP_P1.25mm_Horizontal
JP1: CAN TERM; SolderJumper-2_P1.3mm_Open_Pad1.0x1.5mm
R18: 0R; R_0402_1005Metric
R19, R20: 0R; R_0603_1608Metric
R21: 120R; R_0603_1608Metric
TP17: CAN_H; TestPoint_Pad_D1.0mm
TP18: CAN_L; TestPoint_Pad_D1.0mm
U7: TCAN3413DR; SOIC-8_3.9x4.9mm_P1.27mm; MPN TCAN3413DR
U10: PESD2CANFD24VT-Q; SOT-23; MPN PESD2CANFD24VT-Q

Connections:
3V3_MAIN: C23.1, C24.1, U7.3 (VCC), U7.5 (VIO); also elsewhere on the board
/MFC_G474 SYSTEM/CAN-FD MODULE BUS/CAN_H: J2.3, R19.2, R21.1, TP17.1 (1_1), U10.1 (CANH)
/MFC_G474 SYSTEM/CAN-FD MODULE BUS/CAN_H_PHY: R19.1, U7.7 (CANH)
/MFC_G474 SYSTEM/CAN-FD MODULE BUS/CAN_L: J2.4, JP1.2 (B), R20.2, TP18.1 (1_1), U10.3 (CANL)
/MFC_G474 SYSTEM/CAN-FD MODULE BUS/CAN_L_PHY: R20.1, U7.6 (CANL)
/MFC_G474 SYSTEM/CAN-FD MODULE BUS/CAN_TERM_MID: JP1.1 (A), R21.2
/MFC_G474 SYSTEM/CAN-FD MODULE BUS/TCAN_TXD: R18.2, U7.1 (TXD)
FDCAN_RX: U7.4 (RXD); also elsewhere on the board
FDCAN_TX: R18.1; also elsewhere on the board
GND: C23.2, C24.2, J2.2, U7.2 (GND), U7.8 (STB), U10.2 (GND); also elsewhere on the board
VBAT_PROTECTED: J2.1; also elsewhere on the board

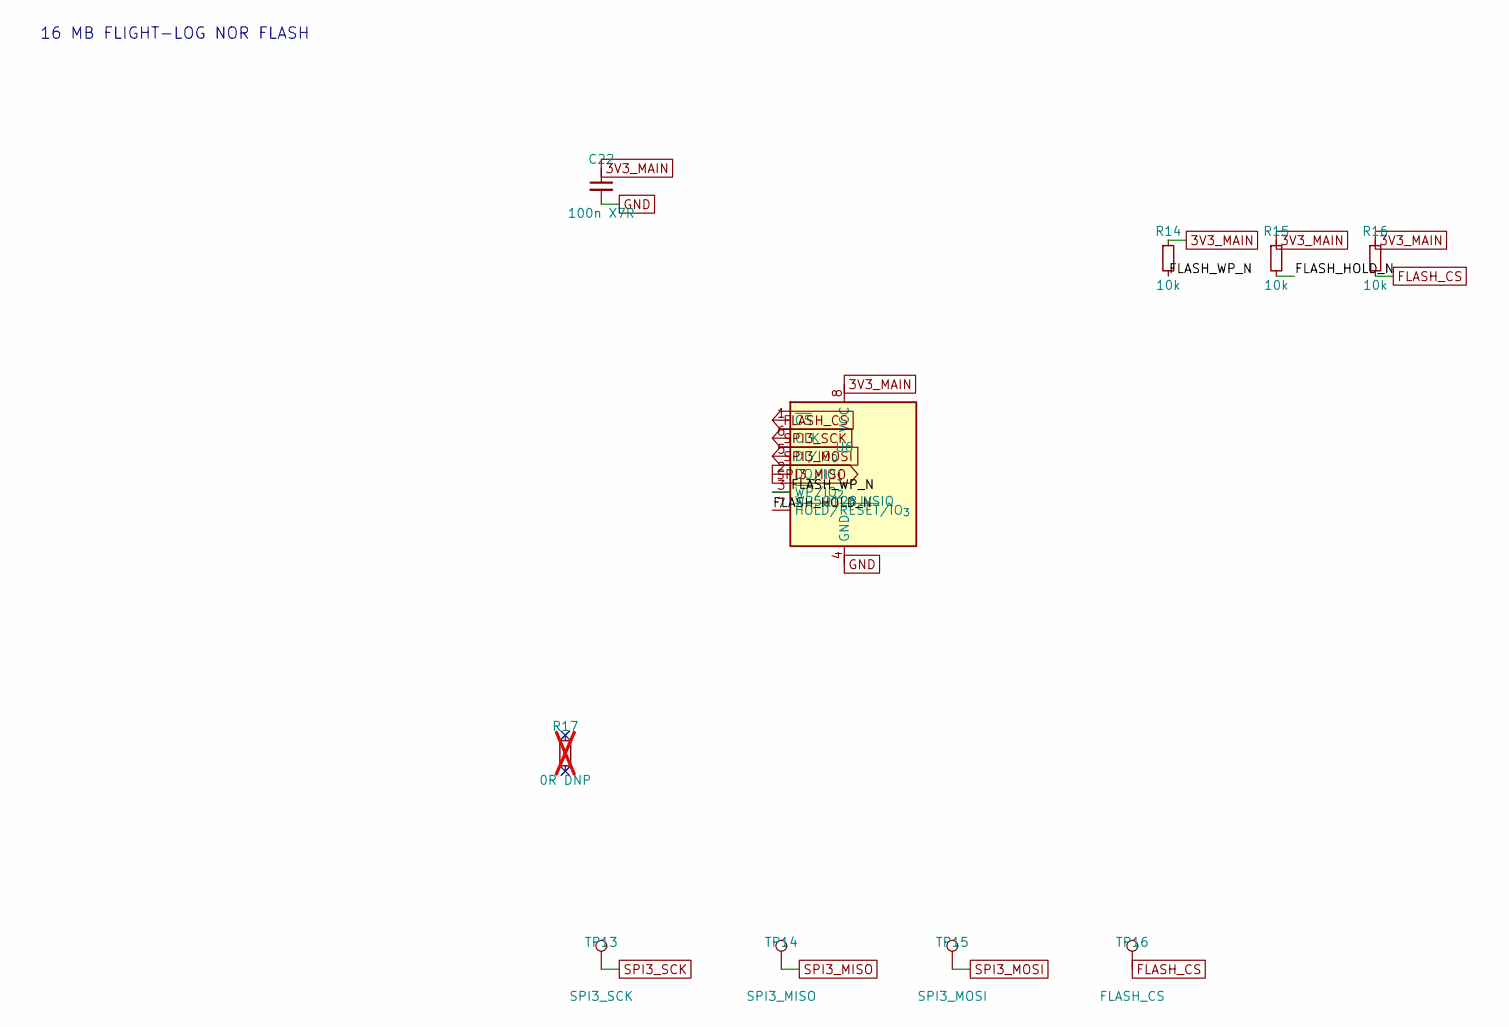
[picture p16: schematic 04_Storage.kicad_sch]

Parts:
C22: 100n X7R; C_0402_1005Metric
R14, R15, R16: 10k; R_0402_1005Metric
R17: 0R DNP; R_0402_1005Metric; not fitted
TP13: SPI3_SCK; TestPoint_Pad_D1.0mm
TP14: SPI3_MISO; TestPoint_Pad_D1.0mm
TP15: SPI3_MOSI; TestPoint_Pad_D1.0mm
TP16: FLASH_CS; TestPoint_Pad_D1.0mm
U6: W25Q128JVSIQ; SOIC-8_5.3x5.3mm_P1.27mm; MPN W25Q128JVSIQ

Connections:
3V3_MAIN: C22.1, R14.1, R15.1, R16.1, U6.8 (VCC); also elsewhere on the board
/MFC_G474 SYSTEM/FLIGHT-LOG STORAGE/FLASH_HOLD_N: R15.2, U6.7 (~HOLD/~RESET/IO_{3})
/MFC_G474 SYSTEM/FLIGHT-LOG STORAGE/FLASH_WP_N: R14.2, U6.3 (~WP/IO_{2})
FLASH_CS: R16.2, TP16.1 (1_1), U6.1 (~CS); also elsewhere on the board
GND: C22.2, U6.4 (GND); also elsewhere on the board
SPI3_MISO: TP14.1 (1_1), U6.2 (DO/IO_{1}); also elsewhere on the board
SPI3_MOSI: TP15.1 (1_1), U6.5 (DI/IO_{0}); also elsewhere on the board
SPI3_SCK: TP13.1 (1_1), U6.6 (CLK); also elsewhere on the board

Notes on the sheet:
16 MB FLIGHT-LOG NOR FLASH

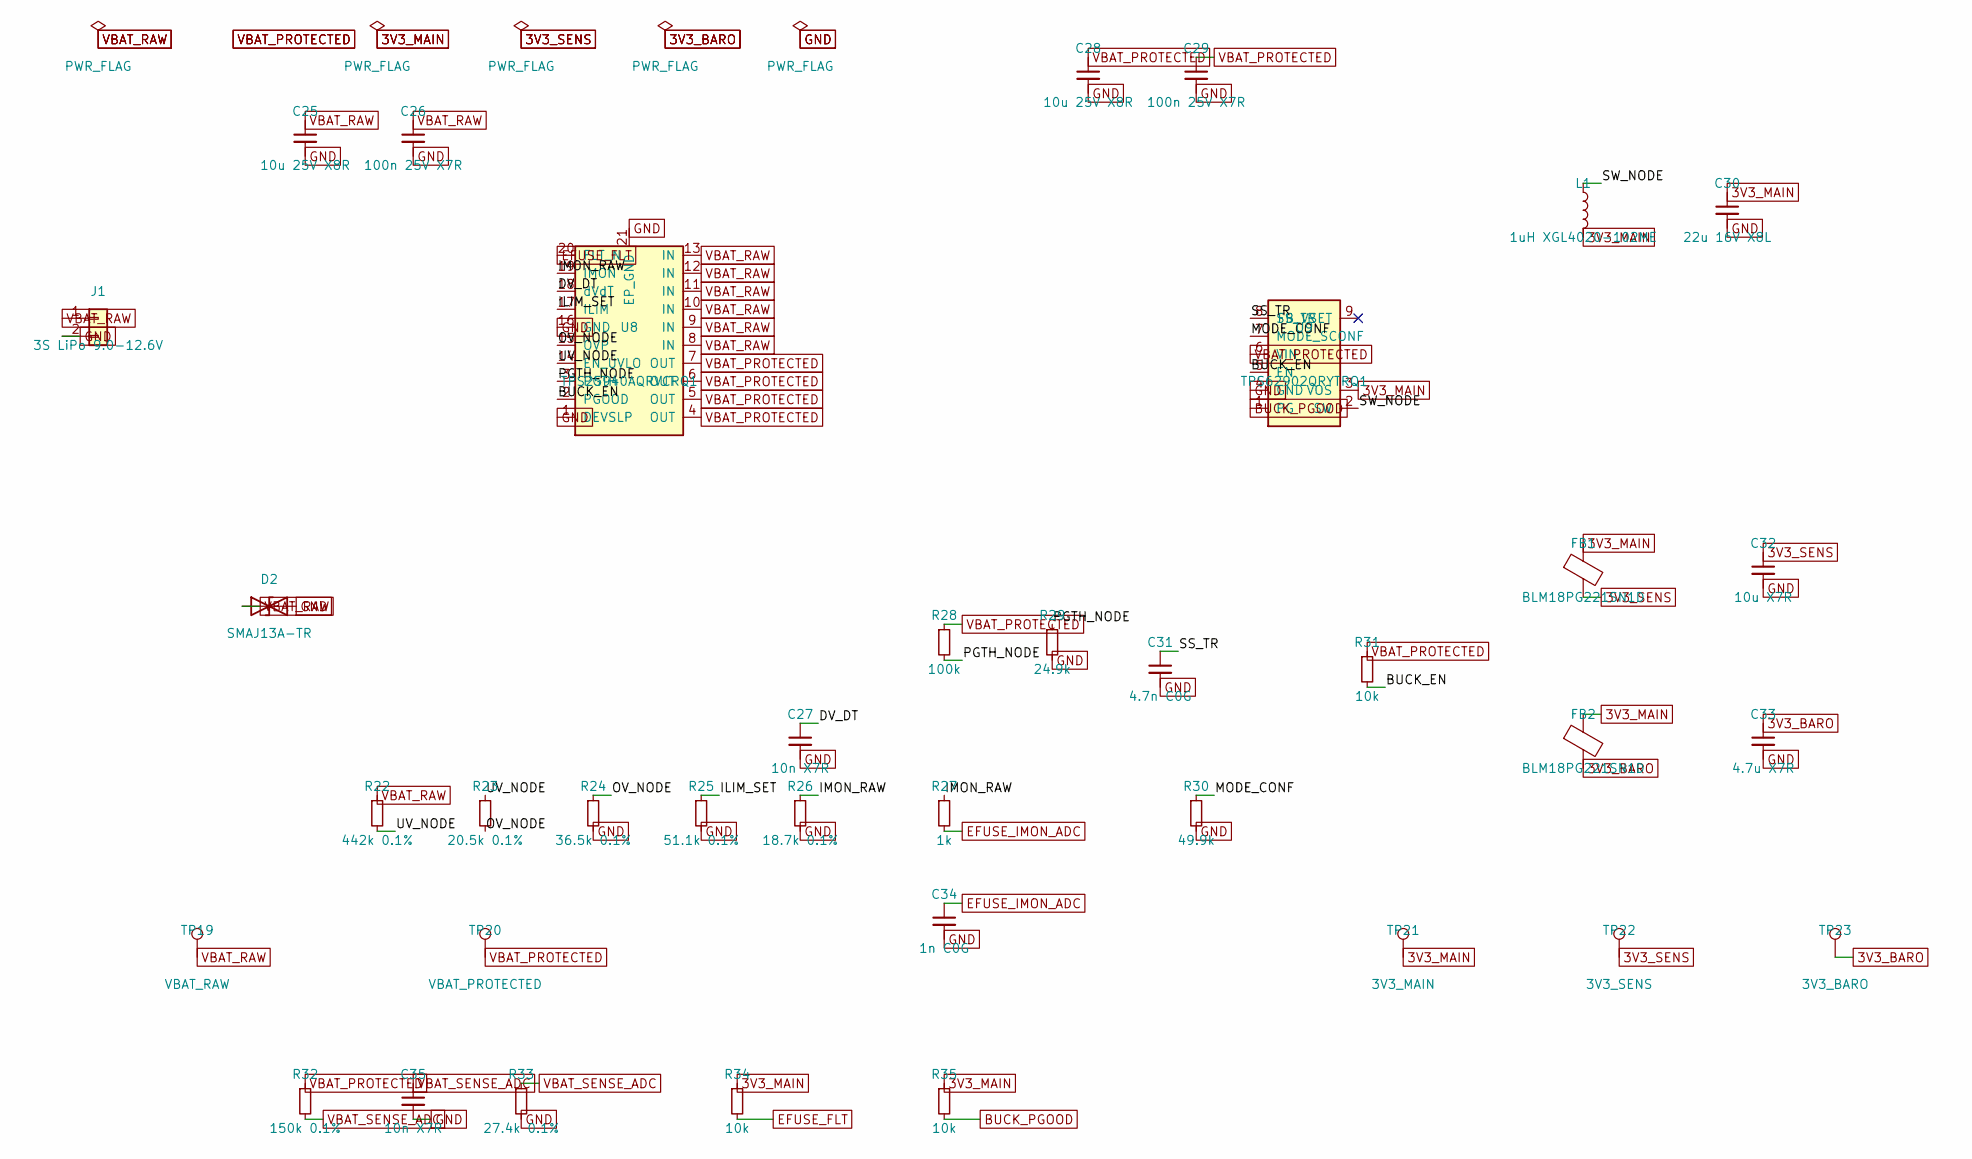
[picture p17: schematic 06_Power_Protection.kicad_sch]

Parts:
C25, C28: 10u 25V X8R; C_1210_3225Metric
C26, C29: 100n 25V X7R; C_0603_1608Metric
C27, C35: 10n X7R; C_0402_1005Metric
C30: 22u 16V X8L; C_1210_3225Metric
C31: 4.7n C0G; C_0402_1005Metric
C32: 10u X7R; C_0805_2012Metric
C33: 4.7u X7R; C_0603_1608Metric
C34: 1n C0G; C_0402_1005Metric
D2: SMAJ13A-TR; D_SMA; MPN SMAJ13A-TR
FB1, FB2: BLM18PG221SN1D; L_0603_1608Metric_Pad1.05x0.95mm_HandSolder; MPN BLM18PG221SN1D
J1: 3S LiPo 9.0-12.6V; HPR_MicroFit_2P_Edge
L1: 1uH XGL4020-102ME; L_Coilcraft_XxL4020; MPN XGL4020-102ME
R22: 442k 0.1%; R_0402_1005Metric
R23: 20.5k 0.1%; R_0402_1005Metric
R24: 36.5k 0.1%; R_0402_1005Metric
R25: 51.1k 0.1%; R_0402_1005Metric
R26: 18.7k 0.1%; R_0402_1005Metric
R27: 1k; R_0402_1005Metric
R28: 100k; R_0402_1005Metric
R29: 24.9k; R_0402_1005Metric
R30: 49.9k; R_0402_1005Metric
R31, R34, R35: 10k; R_0402_1005Metric
R32: 150k 0.1%; R_0402_1005Metric
R33: 27.4k 0.1%; R_0402_1005Metric
TP19: VBAT_RAW; TestPoint_Pad_D1.5mm
TP20: VBAT_PROTECTED; TestPoint_Pad_D1.5mm
TP21: 3V3_MAIN; TestPoint_Pad_D1.5mm
TP22: 3V3_SENS; TestPoint_Pad_D1.0mm
TP23: 3V3_BARO; TestPoint_Pad_D1.0mm
U8: TPS25940AQRVCRQ1; HPR_U8_verified_geometry; MPN TPS25940AQRVCRQ1
U9: TPS62902QRYTRQ1; Texas_RYT0009A_VQFN-HR-9_2.2x2.0mm_P0.5mm; MPN TPS62902QRYTRQ1

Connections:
3V3_BARO: C33.1, FB2.2, TP23.1 (1_1); also elsewhere on the board
3V3_MAIN: C30.1, FB1.1, FB2.1, L1.2, R34.1, R35.1, TP21.1 (1_1), U9.3 (VOS); also elsewhere on the board
3V3_SENS: C32.1, FB1.2, TP22.1 (1_1); also elsewhere on the board
/MFC_G474 SYSTEM/POWER / PROTECTION/BUCK_EN: R31.2, U8.2 (PGOOD), U9.5 (EN)
/MFC_G474 SYSTEM/POWER / PROTECTION/DV_DT: C27.1, U8.18 (dVdT)
/MFC_G474 SYSTEM/POWER / PROTECTION/ILIM_SET: R25.1, U8.17 (ILIM)
/MFC_G474 SYSTEM/POWER / PROTECTION/IMON_RAW: R26.1, R27.1, U8.19 (IMON)
/MFC_G474 SYSTEM/POWER / PROTECTION/MODE_CONF: R30.1, U9.7 (MODE_SCONF)
/MFC_G474 SYSTEM/POWER / PROTECTION/OV_NODE: R23.2, R24.1, U8.15 (OVP)
/MFC_G474 SYSTEM/POWER / PROTECTION/PGTH_NODE: R28.2, R29.1, U8.3 (PGTH)
/MFC_G474 SYSTEM/POWER / PROTECTION/SS_TR: C31.1, U9.8 (SS_TR)
/MFC_G474 SYSTEM/POWER / PROTECTION/SW_NODE: L1.1, U9.2 (SW)
/MFC_G474 SYSTEM/POWER / PROTECTION/UV_NODE: R22.2, R23.1, U8.14 (EN_UVLO)
BUCK_PGOOD: R35.2, U9.1 (PG); also elsewhere on the board
EFUSE_FLT: R34.2, U8.20 (FLT_N); also elsewhere on the board
EFUSE_IMON_ADC: C34.1, R27.2; also elsewhere on the board
GND: C25.2, C26.2, C27.2, C28.2, C29.2, C30.2, C31.2, C32.2, C33.2, C34.2, C35.2, D2.2 (A2), J1.2, R24.2, R25.2, R26.2, R29.2, R30.2, R33.2, U8.1 (DEVSLP), U8.16 (GND), U8.21 (EP_GND), U9.4 (GND); also elsewhere on the board
VBAT_PROTECTED: C28.1, C29.1, R28.1, R31.1, R32.1, TP20.1 (1_1), U8.4 (OUT), U8.5 (OUT), U8.6 (OUT), U8.7 (OUT), U9.6 (VIN); also elsewhere on the board
VBAT_RAW: C25.1, C26.1, D2.1 (A1), J1.1, R22.1, TP19.1 (1_1), U8.8 (IN), U8.9 (IN), U8.10 (IN), U8.11 (IN), U8.12 (IN), U8.13 (IN)
VBAT_SENSE_ADC: C35.1, R32.2, R33.1; also elsewhere on the board

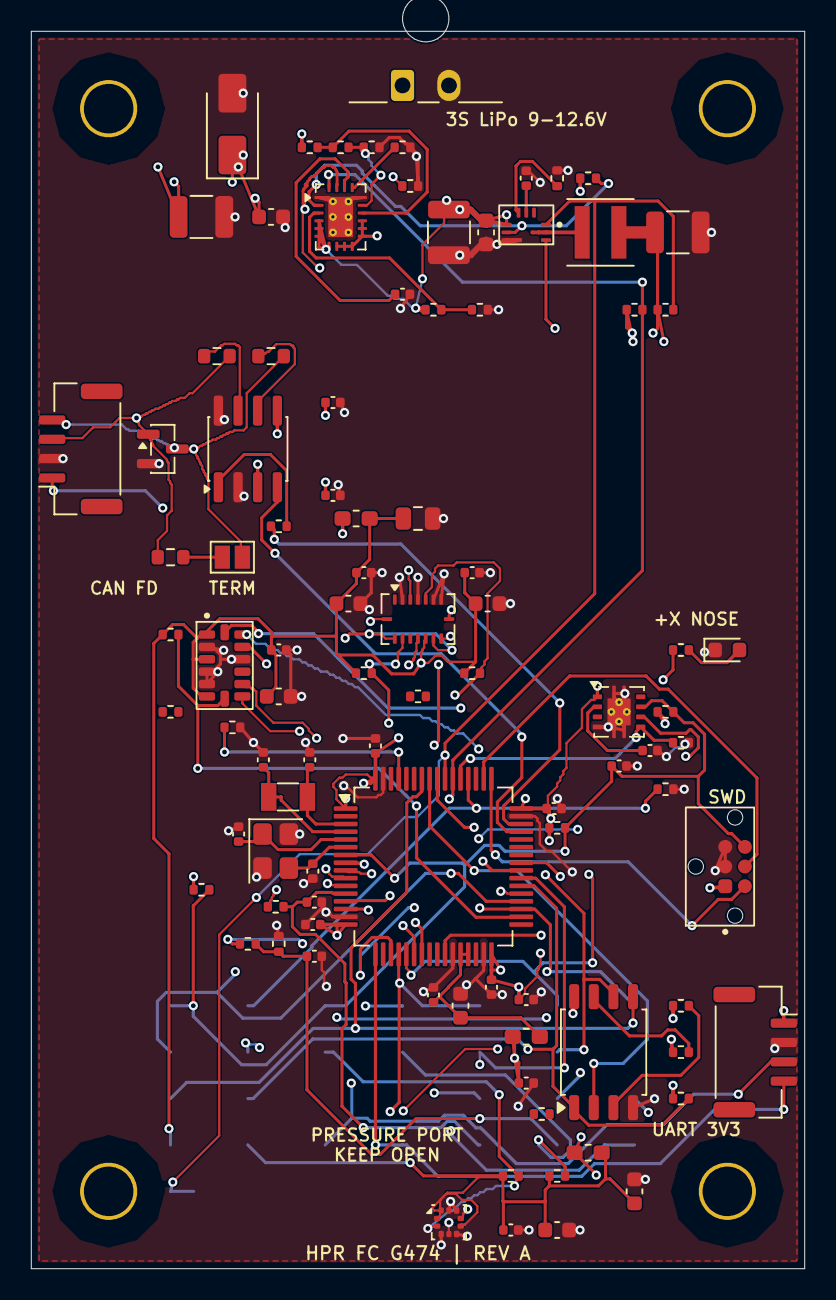
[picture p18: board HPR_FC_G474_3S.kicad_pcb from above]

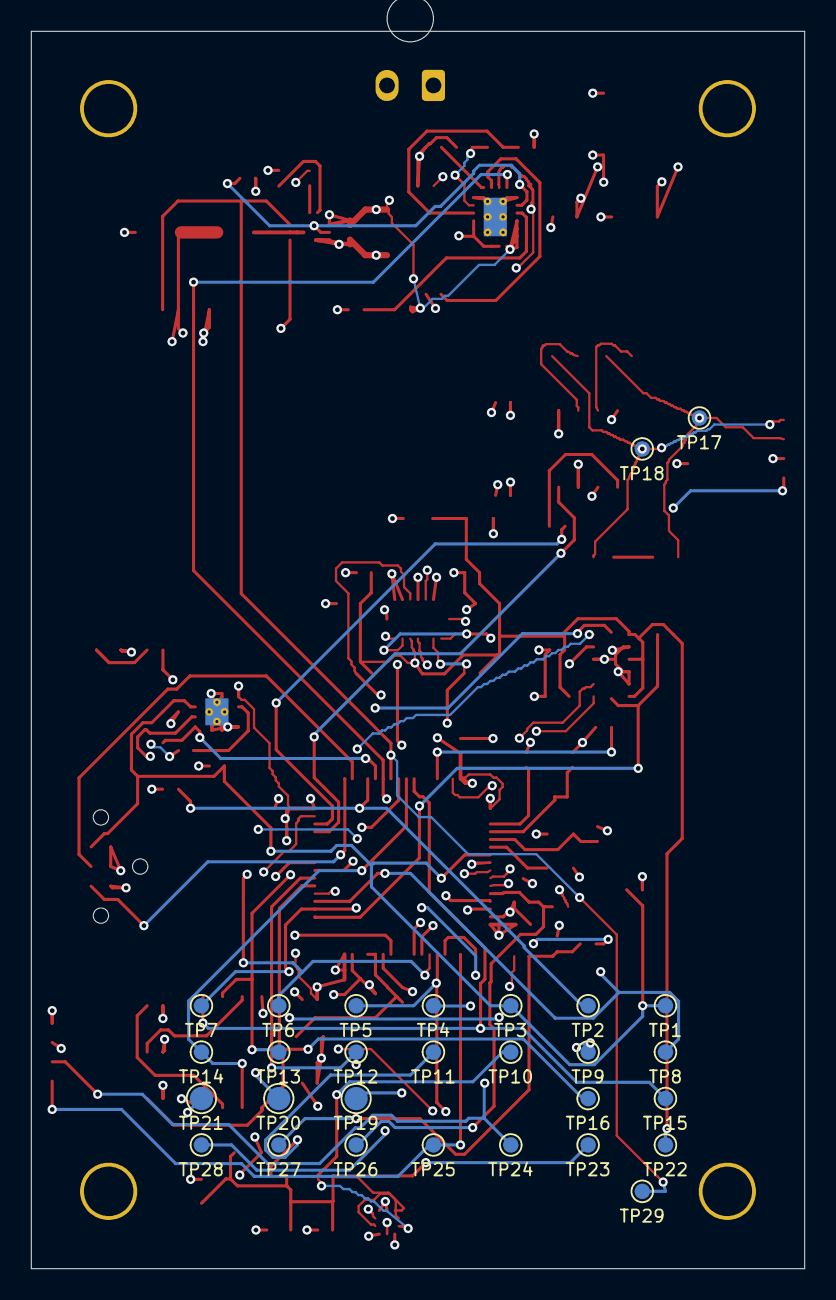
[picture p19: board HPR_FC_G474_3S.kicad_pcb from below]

Board: 4 copper layers, 50.0 x 80.0 mm, 127 parts (29 on the bottom side), 66 nets.

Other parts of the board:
H1: MountingHole; HPR_H1_verified_geometry
H2: MountingHole; HPR_H2_verified_geometry
H3: MountingHole; HPR_H3_verified_geometry
H4: MountingHole; HPR_H4_verified_geometry
